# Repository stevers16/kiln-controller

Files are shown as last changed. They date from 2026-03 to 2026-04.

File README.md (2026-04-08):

# Kiln Controller

A MicroPython-based lumber drying kiln controller for a passive solar kiln in the
Georgian Bay area of Ontario. Designed for drying hardwood lumber (maple and beech,
0.5--1 inch thick) using multi-stage schedules derived from USDA Forest Products
Laboratory references (FPL-GTR-57 and FPL-GTR-118).

The kiln is approximately 5 ft x 2 ft x 3 ft, heated passively by solar gain with a
500W ceramic PTC backup heater for shoulder-season use. A Raspberry Pi Pico 2W
controls all kiln hardware. Telemetry is transmitted over LoRa (~200m) to a Raspberry
Pi 4 at the cottage, which stores data in SQLite and serves a REST API for a Kivy
mobile app.

---

## Hardware

| Subsystem | Component |
|---|---|
| MCU | Raspberry Pi Pico 2W |
| Temperature / RH | 2x SHT31-D (I2C, 0x44 / 0x45) |
| Moisture probes | Resistive, voltage divider, AC excitation |
| Exhaust fan | Foxconn PVA080G12Q 80mm PWM, tach feedback |
| Circulation fans | 3x Thermalright TL-C12C 120mm PWM |
| Vent dampers | 2x MG90S servo (intake + exhaust) |
| Backup heater | 500W PTC + Fotek SSR-25DA + RY85 thermal fuse |
| Current monitoring | 2x INA219 (12V rail + 5V rail) |
| Display | JC035-HVGA-ST-02 3.5" UART serial, 320x480 |
| SD card | SPI micro SD (logging) |
| LoRa radio | AI-Thinker Ra-02 433 MHz (SX1278), TX-only |
| Remote server | Raspberry Pi 4 with Ra-02 receiver |

---

## Schematic and custom PCB

KiCad 9.0 project with schematic and custom PCB layout is in the PCB folder.

---

## Firmware (Pico 2W -- MicroPython)

All hardware drivers live in `lib/`. Every module is class-based, accepts pin numbers
as constructor arguments, and follows the pattern established in `lib/exhaust.py`.

| Module | Function |
|---|---|
| `lib/exhaust.py` | 80mm exhaust fan -- PWM + tach |
| `lib/circulation.py` | 3x 120mm circulation fans -- PWM group |
| `lib/vents.py` | Intake + exhaust damper servos |
| `lib/heater.py` | SSR on/off control |
| `lib/SHT31sensors.py` | Dual SHT31 temperature + RH |
| `lib/moisture.py` | Resistive moisture probes, species correction |
| `lib/current.py` | INA219 DC current monitoring |
| `lib/lora.py` | SX1278 LoRa transmitter (TX-only, register polling) |
| `lib/display.py` | UART serial display driver + button + page system |
| `lib/sdcard.py` | SPI SD card mount/unmount wrapper |
| `lib/logger.py` | Event log + CSV data log to SD card |
| `lib/schedule.py` | Multi-stage drying schedule controller |
| `main.py` | Entry point -- asyncio control loop + WiFi AP + REST API |
| `config.py` | Deployment configuration (SSID, key, LoRa params) |

Drying schedules are stored as JSON in `schedules/` and loaded from the SD card at
runtime. Schedules are included for hard maple and beech at 0.5 in and 1 in thickness.

### Deploying to the Pico

```
python update_lib.py
```

This copies `main.py`, `config.py`, and all `lib/` files to the Pico in one step.
The MicroPython SPI SD card driver must be deployed as `sdcard_driver.py`:

```
mpremote cp sdcard_driver.py :sdcard_driver.py
```

### Running tests

```
mpremote run test_modules.py
```

Tests all 12 modules in sequence and reports pass/fail. Does not start WiFi or the
control loop.

---

## Cottage-side architecture (Pi4)

```
Pico --> SPI1 --> Ra-02 ~~LoRa~~ Ra-02 --> SPI0 --> Pi4 kiln_server
                                                 --> SQLite
                                                 --> REST API :8080 --> Kivy app
                                                 --> ntfy.sh --> phone
```

The `kiln_server/` Python package (in progress) runs as a systemd service on the Pi4.
It receives LoRa packets from the Pico, writes telemetry and alerts to SQLite, serves
a REST API for the mobile app, and pushes fault alerts via ntfy.sh.

The Pico also runs a WiFi AP and exposes its own REST API (port 80) for direct
local control when within range.

---

## Drying schedules

Schedules follow USDA FPL kiln-drying recommendations:

- Hard maple (T3-C2): `schedules/maple_05in.json`, `schedules/maple_1in.json`
- Beech (T4-C3): `schedules/beech_05in.json`, `schedules/beech_1in.json`

Each schedule has 9 stages: 7 drying stages + equalizing + conditioning. Stage advance
is automatic (MC% + minimum time) for drying stages, and time-only for
equalizing/conditioning. Manual advance is available via the REST API.

---

## Status

Pico firmware is at the integration stage. All 12 `lib/` modules are complete and
hardware-tested. `main.py` is implemented and pending full hardware integration test.
The Pi4 `kiln_server` daemon and Kivy mobile app are next.

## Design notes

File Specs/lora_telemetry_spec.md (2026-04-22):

# LoRa Telemetry Module -- Hardware & Firmware Spec
**Kiln Controller Project**
**Status:** Ra-02 modules on order (arriving ~2 weeks); Pi4 daemon not yet implemented
**Scope:** Covers Pico-side LoRa transmitter and Pi4-side LoRa receiver + data server

---

## Overview

The kiln Pico 2W transmits periodic telemetry and fault alerts via a LoRa radio link to a
Raspberry Pi 4 at the cottage (~200m, wooded path following cleared driveway). The Pi4 has
a second Ra-02 module wired directly to its SPI bus. A Python daemon receives LoRa packets,
writes them to a SQLite database, serves a REST API for the Kivy phone app, and pushes
fault alerts via ntfy.sh.

```
Pico 2W --> SPI1 --> Ra-02 (433 MHz) ~~LoRa~~ Ra-02 --> SPI0 --> Pi4 daemon --> SQLite
                                                                              --> REST API --> Kivy app
                                                                              --> ntfy.sh --> phone
```

**Pico-side is transmit-only.** The Pico never listens for incoming LoRa packets. All
parameter changes and commands to the kiln are handled via the Wi-Fi AP / REST API interface.
DIO0 is not connected on the Pico side -- TX completion is confirmed by polling the SX1278
IRQ flags register over SPI (see Firmware section). This frees GP20 for use as the display
button input.

No ESP32 or MQTT broker is required in the deployed system. The ESP32-WROOM-32 devboard
(owned) is useful for bench testing the Pico LoRa transmitter before the Pi4 daemon is
ready, but is not part of the production architecture.

---

## Hardware

### LoRa Modules

**Part:** AI-Thinker Ra-02 (SX1278, 433 MHz) with IPEX antenna
**Quantity:** 2 (ordered from AliExpress)
**Critical:** 433 MHz variant only -- NOT the 915 MHz Ra-01 or Ra-01S.

**Ra-02 electrical characteristics:**
- Supply voltage: 3.3V (NOT 5V tolerant -- will be damaged by 5V)
- Logic levels: 3.3V
- Interface: SPI (mode 0)
- Max SPI clock: 10 MHz (use 1-4 MHz in practice)
- Current draw: ~120 mA TX, ~12 mA RX, ~1.5 mA idle

**Antenna:** IPEX (u.FL) connector with antenna included in order.

---

### Pico-Side Wiring (Kiln Enclosure)

The Ra-02 connects via SPI1 on the Pico using the default SPI1 pin block (GP10-GP13).
Moisture probe AC excitation channels were moved from GP12/GP13 to GP6/GP7 to free the
full SPI1 block for LoRa -- this is already reflected in `lib/moisture.py` (GP6/GP7).

DIO0 is **not connected** on the Pico side. TX completion is confirmed by polling the
SX1278 IRQ flags register over SPI (see Firmware section). GP20 is therefore free for
use as the display button input, which is its current assignment in `lib/display.py`.

**Power:**

| Ra-02 Pin | Pico Pin | Notes |
|---|---|---|
| VCC | 3.3V (Pin 36) | Ra-02 is 3.3V only  |
| GND | GND (Pin 38)  | Common ground |

**SPI and control:**

| Ra-02 Pin | Pico GPIO | Physical Pin | Notes |
|---|---|---|---|
| SCK | GP10 | Pin 14 | SPI1 SCK (default) |
| MOSI | GP11 | Pin 15 | SPI1 TX (default) |
| MISO | GP12 | Pin 16 | SPI1 RX (default) |
| NSS (CS)  | GP13 | Pin 17 | SPI1 CS (default) -- active low |
| RST | GP28 | Pin 34 | Reset -- active low |
| DIO0 | -- | not connected| Not needed (TX-only, polling) |

**GPIO map (Pico GPIO Map tab in BOM):**

| GPIO | Function | Notes |
|---|---|---|
| GP6  | Digital OUT -- AC excite Ch1  | Moisture probe (moved from GP12) |
| GP7  | Digital OUT -- AC excite Ch2  | Moisture probe (moved from GP13) |
| GP10 | SPI1 SCK -- LoRa Ra-02 | |
| GP11 | SPI1 TX (MOSI) -- LoRa Ra-02  | |
| GP12 | SPI1 RX (MISO) -- LoRa Ra-02  | |
| GP13 | SPI1 CS -- LoRa Ra-02 | Active low |
| GP20 | Digital IN -- Display button  | Freed from LoRa DIO0; see display spec |
| GP28 | Digital OUT -- LoRa RST | |

**Decoupling:** Place a 100 nF ceramic capacitor between Ra-02 VCC and GND as close to
the module as possible. The Ra-02 RF switching causes supply transients.

---

### Pi4-Side Wiring (Cottage)

The Ra-02 wires directly to the Pi4 GPIO header via SPI0. The Pi4 GPIO is 3.3V -- no
level shifting required. SPI must be enabled on the Pi4 via:
`sudo raspi-config` -> Interface Options -> SPI -> Enable

DIO0 IS connected on the Pi4 side because the daemon uses interrupt-driven receive.

**Power:**

| Ra-02 Pin | Pi4 Pin | Notes |
|---|---|---|
| VCC | Pin 17 (3.3V) | Ra-02 is 3.3V only |
| GND | Pin 20 (GND)  | Common ground |

**SPI and control (SPI0, CE0):**

| Ra-02 Pin | Pi4 GPIO | Pi4 Physical Pin | Notes |
|---|---|---|---|
| SCK | GPIO11 | Pin 23 | SPI0 SCLK |
| MOSI | GPIO10 | Pin 19 | SPI0 MOSI |
| MISO | GPIO9 | Pin 21 | SPI0 MISO |
| NSS (CS)  | GPIO8 | Pin 24 | SPI0 CE0 -- active low |
| DIO0 | GPIO25 | Pin 22 | RX done interrupt (input) |
| RST | GPIO17 | Pin 11 | Reset line (output) |

**Decoupling:** 100 nF ceramic capacitor between Ra-02 VCC and GND.

---

## Firmware Architecture

### Pico Side -- `lib/lora.py`

A mock implementation already exists and passes hardware tests. This section describes
the real driver to replace it once Ra-02 hardware arrives. Follow the existing module
pattern (class-based, pin numbers as constructor args, matching `exhaust.py` template).

```python
# Instantiation example (from main.py)
lora = LoRa(
    spi_id=1,
    sck=10, mosi=11, miso=12,
    cs=13, rst=28,
    frequency=433_000_000
)
```

Note: no `irq` parameter -- DIO0 is not connected on the Pico side.

**Class responsibilities:**
- Initialise SPI1 using default pin block:
  `SPI(1, baudrate=1_000_000, sck=Pin(10), mosi=Pin(11), miso=Pin(12))`
- Configure SX1278 registers via SPI (frequency, bandwidth, spreading factor, coding rate)
- `send(payload: bytes) -> bool` -- blocking TX with polling-based completion (see below)
- `send_telemetry(data: dict) -> bool` -- serialises dict to JSON, calls `send()`
- `send_alert(code: str, message: str) -> bool` -- 3x retry with 2s spacing
- `reset()` -- pulses RST pin low for 10ms
- `is_mock` property returns False (distinguishes from mock implementation)
- TX-only -- no receive path on Pico side
- Accepts optional `logger=None`; source string `"lora"`; logs on init, send success,
  send timeout, and RST events

**TX completion -- register polling (no DIO0 needed):**

Because DIO0 is not connected, TX completion is determined by polling the SX1278 IRQ flags
register (RegIrqFlags, address 0x12) over SPI. The TxDone flag is bit 3 (mask 0x08).

Procedure in `send()`:
1. Write payload to FIFO, set mode to TX (RegOpMode = 0x83)
2. Poll RegIrqFlags in a loop at 5 ms intervals until bit 3 (TxDone) is set, or 2000 ms
   timeout is reached
3. Clear all IRQ flags by writing 0xFF to RegIrqFlags
4. Return device to sleep mode (RegOpMode = 0x80)
5. Return True on TxDone, False on timeout (caller logs `LORA_TIMEOUT` alert)

For SF9 / 125 kHz / 4:5 coding rate, airtime for a 100-byte payload is approximately
330 ms. The 2000 ms timeout gives comfortable headroom across all expected payload sizes.
This approach is functionally equivalent to interrupt-driven TX confirmation for a
transmit-only module on a 30-second heartbeat schedule.

**Suggested LoRa RF parameters:**

| Parameter | Value | Notes |
|---|---|---|
| Frequency | 433.0 MHz | Within 433.05-434.79 MHz ISM band (Canada RSS-210) |
| Bandwidth | 125 kHz | Standard |
| Spreading Factor | SF9 | Good for wooded 200m; increase if link marginal |
| Coding Rate | 4/5 | |
| TX Power | 17 dBm | Ra-02 maximum; reduce if interference observed |
| Preamble | 8 symbols | Default |

**Transmission schedule:**
- Telemetry heartbeat: every 30 seconds (driven by `schedule.py` tick)
- Fault alerts: immediate on detection, retried up to 3x with 2s spacing
- SPI1 (LoRa) and SPI0 (SD card) are separate buses -- no contention

**Fault codes in telemetry packet (added by error_checking_spec.md):**

The LoRa telemetry packet now includes an optional `faults` field: a flat
JSON array of fault code strings (e.g. `"faults":["SD_FAIL","LORA_TIMEOUT"]`).
Only tier="fault" codes are included (not notices or info). The list is
trimmed from the back until the total packet fits within the SX1278 255-byte
FIFO limit. With the existing ~231-byte base payload, typically 0-1 short
fault codes fit. If no faults are active, the field is omitted entirely.

The rich `fault_details` list (with code, source, message, tier per fault)
is served exclusively over the Pico HTTP `/status` endpoint. The Pi4 daemon
receives only the flat code list over LoRa and can look up descriptions
from a static table or simply display the codes.

**Duty cycle note:** At 30s intervals TX duty cycle is well under 1% -- within the 10%
limit for 433 MHz ISM use in Canada.

---

### Pi4 Side -- `kiln_server/` Python package

The Pi4 runs a single Python process that owns the Ra-02 via SPI, writes all received
data to SQLite, serves a REST API to the Kivy app, and pushes alerts via ntfy.sh.

**Python dependencies:**
- `spidev` -- SPI bus access on Pi4
- `RPi.GPIO` -- GPIO interrupt handling for DIO0
- `pysx127x` or equivalent SX1276/78 driver (or port register sequences from the Pico
  driver directly -- keeps both sides symmetric and eliminates a third-party dependency)
- `flask` or `fastapi` -- REST API
- `requests` -- ntfy.sh HTTP POST
- `sqlite3` -- stdlib, no install required

**Package structure:**

```
kiln_server/
  __main__.py       -- entry point; starts receiver loop and REST API server
  config.py         -- Pi4 GPIO pins, DB path, ntfy topic, API port, LoRa params
  lora_receiver.py  -- SX1278 init, receive loop, DIO0 interrupt handler
  database.py       -- SQLite open/init, insert_telemetry(), insert_alert(), query functions
  api.py            -- REST route definitions
  notifier.py       -- ntfy.sh POST helper
  schema.sql        -- SQLite CREATE TABLE statements (also executed by database.py on init)
```

**`config.py` (the only file that changes between bench and cottage deployment):**

```python
# Bench Pi4 (home)
DB_PATH       = "/home/srelias/CottageKiln/kiln_data.db"
NTFY_TOPIC    = "your-unique-kiln-topic"
API_PORT      = 8080

# Pi4 GPIO pin numbers (BCM numbering -- same on bench and cottage)
LORA_RST_PIN  = 17
LORA_DIO0_PIN = 25
LORA_SPI_BUS  = 0
LORA_SPI_DEV  = 0    # CE0

# LoRa RF params -- must match Pico side
LORA_FREQ_HZ  = 433_000_000
LORA_SF       = 9
LORA_BW_HZ    = 125_000
```

**Operation:**
1. On start: initialise Ra-02 via SPI, configure for continuous receive mode
2. DIO0 interrupt fires on packet received -> read payload, parse JSON
3. Write telemetry record to SQLite `telemetry` table with Pi4 wall-clock timestamp
4. If packet is an alert, write to `alerts` table and POST to ntfy.sh
5. REST API runs concurrently (thread or async) serving Kivy app queries
6. Daemon runs continuously; started at boot via systemd unit file

---

## SQLite Schema

```sql
-- schema.sql

CREATE TABLE IF NOT EXISTS telemetry (
    id              INTEGER PRIMARY KEY AUTOINCREMENT,
    ts              INTEGER NOT NULL,   -- Unix timestamp from Pico RTC
    received_at     INTEGER NOT NULL,   -- Unix timestamp on Pi4 (wall clock)
    stage           TEXT,
    temp_lumber     REAL,
    temp_intake     REAL,
    humidity_lumber REAL,
    humidity_intake REAL,
    mc_channel_1    REAL,
    mc_channel_2    REAL,
    exhaust_fan_rpm INTEGER,
    exhaust_fan_pct INTEGER,
    circ_fan_on     INTEGER,            -- 0/1
    heater_on       INTEGER,            -- 0/1
    vent_open       INTEGER,            -- 0/1
    lora_rssi       INTEGER,            -- dBm, measured at Pi4 receiver
    lora_snr        REAL
);

CREATE TABLE IF NOT EXISTS alerts (
    id          INTEGER PRIMARY KEY AUTOINCREMENT,
    ts          INTEGER NOT NULL,
    received_at INTEGER NOT NULL,
    code        TEXT NOT NULL,
    message     TEXT,
    value       REAL,
    limit_val   REAL,
    lora_rssi   INTEGER,
    lora_snr    REAL
);

CREATE TABLE IF NOT EXISTS runs (
    id            INTEGER PRIMARY KEY AUTOINCREMENT,
    started_at    INTEGER NOT NULL,
    ended_at      INTEGER,
    schedule_name TEXT,
    completed     INTEGER DEFAULT 0     -- 0/1
);

CREATE INDEX IF NOT EXISTS idx_telemetry_ts ON telemetry(ts);
CREATE INDEX IF NOT EXISTS idx_alerts_ts    ON alerts(ts);
```

---

## REST API Endpoints

Base URL: `http://<pi4-ip>:8080`

All responses are JSON.

| Method | Path | Description |
|---|---|---|
| GET | `/status`  | Latest telemetry record |
| GET | `/history` | Time-series data; params: `start`, `end` (Unix ts), `fields` (CSV list)|
| GET | `/alerts`  | Recent alerts; param: `limit` (default 50) |
| GET | `/runs` | List of drying runs with start/end times |
| GET | `/health`  | Daemon uptime, last packet received timestamp, total packet count |

**Example `/history` response (columnar format for Kivy plotting):**

```json
{
  "fields": ["ts", "temp_lumber", "humidity_lumber", "mc_channel_1"],
  "rows": [
    [1700000000, 52.3, 61.2, 18.4],
    [1700000030, 52.5, 60.9, 18.3]
  ]
}
```

The columnar format minimises payload size for long runs -- more efficient than an array
of objects when plotting hundreds or thousands of data points.

---

## Alert Codes

Alerts are generated on the Pico and transmitted as LoRa packets. The Pi4 daemon writes
them to the `alerts` table and triggers ntfy.sh notifications.

| Code | Source | Condition |
|---|---|---|
| `OVER_TEMP` | Pico | Either SHT31 zone exceeds stage limit |
| `SENSOR_FAIL` | Pico | SHT31 read error or timeout |
| `FAN_STALL` | Pico | Exhaust fan tach reads 0 RPM when commanded on |
| `HEATER_TIMEOUT` | Pico | SSR on continuously beyond safety threshold |
| `SD_FAIL` | Pico | SD card write error |
| `LORA_TIMEOUT` | Pico | TxDone flag not seen within 2000 ms polling window |
| `STAGE_COMPLETE` | Pico | Drying schedule stage transition (informational) |
| `SCHEDULE_DONE`  | Pico | Full drying schedule completed |

---

## Phone Notifications -- ntfy.sh

The Pi4 daemon POSTs directly to ntfy.sh on alert receipt. No MQTT broker or separate
notification script required.

```python
# notifier.py
import requests

def send_alert(topic, code, message):
    try:
        requests.post(
            f"https://ntfy.sh/{topic}",
            data=f"{code}: {message}",
            headers={"Priority": "high", "Tags": "warning"},
            timeout=5
        )
    except Exception:
        pass  # never let notification failure affect daemon operation
```

Install the ntfy app on phone and subscribe to the configured topic name. Alert delivery
is best-effort -- the kiln runs safely whether or not the notification goes through.

---

## Systemd Service

```ini
# /etc/systemd/system/kiln-server.service
[Unit]
Description=Kiln LoRa Telemetry Server
After=network.target

[Service]
ExecStart=/usr/bin/python3 -m kiln_server
WorkingDirectory=/home/srelias/CottageKiln/kiln_server
Restart=always
RestartSec=5
User=pi

[Install]
WantedBy=multi-user.target
```

Enable: `sudo systemctl enable kiln-server && sudo systemctl start kiln-server`

---

## Bench Test Plan

Both Pi4 units are identical -- the bench test exactly duplicates the cottage deployment.
Only `config.py` changes between environments.

**End-to-end bench test:**
1. Wire bench Pi4 to Ra-02 per Pi4 wiring table above
2. Enable SPI: `sudo raspi-config` -> Interface Options -> SPI -> Enable; reboot
3. Install dependencies: `pip install spidev RPi.GPIO flask requests`
4. Start daemon: `python -m kiln_server`
5. Wire Pico to Ra-02 per Pico wiring table (DIO0 unconnected); flash real `lib/lora.py`
6. Run `lora_test.py` on Pico -- transmit a packet every 5s
7. Verify TxDone flag is seen via register polling within expected airtime (~330 ms for 100 bytes at SF9)
8. Confirm rows in SQLite: `sqlite3 kiln_data.db "SELECT * FROM telemetry LIMIT 5;"`
9. Confirm REST API: `curl http://localhost:8080/status`
10. Trigger a test alert from Pico; confirm ntfy.sh notification on phone
11. Force a `LORA_TIMEOUT` by asserting CS high during TX; verify alert code fires correctly
12. Short-range RSSI will be very strong (-40 to -60 dBm) -- that is expected

**Pre-deployment check at cottage:**
1. Deploy cottage Pi4 with identical setup; update `config.py` for cottage network
2. Start `kiln_server` as systemd service
3. Power Pico at kiln location
4. Query `/health` -- watch `last_packet_ts` and packet count increment
5. Target RSSI: better than -115 dBm at SF9. Expect -90 to -105 dBm for 200m wooded path.
6. If RSSI marginal, increase SF to SF10 or SF11 in `config.py` and Pico constructor
   (3-6 dB link budget gain per SF step, at cost of longer air time)

---

## BOM

| Item | Qty | Est. Cost (CAD) | Notes |
|---|-----|---|---|
| AI-Thinker Ra-02 433 MHz + IPEX antenna | 2 | ~$8 | Ordered from AliExpress |
| 100 nF ceramic capacitor | 2 | ~$0.10 | Decoupling; likely in stock |
| Female-female jumper wires | 6 | ~$1 | Pi4 GPIO header connection |

Both Pi4 units are already owned. ESP32-WROOM-32 devboard retained as an optional tool
for bench-testing Pico LoRa TX before the Pi4 daemon is ready; not part of production
system.

---

## Open Items

- [x] Ra-02 modules ordered (arriving ~2 weeks)
- [x] GPIO pin assignments finalised: GP10-13 SPI1, GP28 RST; DIO0 not connected on Pico
- [x] GP20 confirmed as display button (freed from LoRa DIO0)
- [x] Moisture probe AC excitation confirmed on GP6/GP7 in `lib/moisture.py`
- [x] Architecture decision: Ra-02 wired directly to Pi4; no ESP32 in production
- [ ] Implement real `lib/lora.py` on Pico to replace mock (after Ra-02 arrives)
- [ ] Implement `kiln_server/` Python package (Claude Code)
- [ ] Enable SPI on bench Pi4 and wire Ra-02
- [ ] Bench test: Pico TX -> Pi4 RX -> SQLite -> REST API -> ntfy.sh
- [ ] Choose ntfy.sh topic name
- [ ] Write and enable systemd unit file on cottage Pi4
- [ ] Kivy app REST API integration (separate spec, to be written)

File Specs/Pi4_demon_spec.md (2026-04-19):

# PI4_DAEMON_SPEC.md

Spec for the `kiln_server` Python daemon running on the Raspberry Pi 4 at the
cottage. This document supersedes the informal daemon sketch in
`lora_telemetry_spec.md` and adds all endpoints and database details required
by the Kivy app.

---

## Overview

The Pi4 daemon (`kiln_server`) is a long-running Python process that:

1. Receives LoRa telemetry packets from the kiln Pico via a Ra-02 SX1278 module
   wired to the Pi4 SPI0 bus
2. Writes all telemetry and alerts to a SQLite database
3. Serves a read-only REST API (port 8080) for the Kivy app
4. Pushes fault alerts to a phone via ntfy.sh

No control commands are relayed to the Pico from the Pi4. The Pi4 API is
strictly read-only. Control requires direct AP connection from the app to the
Pico.

---

## Package Structure

```
kiln_server/
    __main__.py         -- entry point; starts all threads/tasks
    config.py           -- environment-specific settings (only file that differs
                           between bench and cottage deployments)
    lora_receiver.py    -- SX1278 SPI init, DIO0 interrupt, receive loop
    database.py         -- SQLite schema, insert and query functions
    api.py              -- Flask REST endpoints
    notifier.py         -- ntfy.sh HTTP POST
    schema.sql          -- SQL schema (applied on first run)
```

---

## Hardware

Ra-02 SX1278 wired to Pi4 GPIO header via SPI0. See `lora_telemetry_spec.md`
for full wiring table. SPI must be enabled via `raspi-config`.

---

## config.py

The only file that differs between bench and cottage deployments.

```python
# config.py

ENVIRONMENT   = "cottage"          # "bench" or "cottage" -- shown in /health

# LoRa SPI
SPI_BUS       = 0
SPI_CE        = 0                  # CE0 = GPIO8
DIO0_PIN      = 25                 # GPIO25
RST_PIN       = 17                 # GPIO17
LORA_SF       = 9
LORA_FREQ_MHZ = 433.0

# Database
DB_PATH       = "/home/srelias/CottageKiln/kiln_data.db"

# API
API_HOST      = "0.0.0.0"
API_PORT      = 8080

# Notifications
NTFY_TOPIC    = "kiln-cottage-abc123"   # choose a unique topic name
NTFY_URL      = "https://ntfy.sh"

# Alert suppression (do not re-notify same code within this window)
ALERT_SUPPRESS_S = 1800            # 30 minutes
```

---

## SQLite Schema

Applied from `schema.sql` on first run if tables do not exist.

```sql
CREATE TABLE IF NOT EXISTS telemetry (
    id              INTEGER PRIMARY KEY AUTOINCREMENT,
    ts              INTEGER NOT NULL,       -- Unix timestamp from Pico RTC
    received_at     INTEGER NOT NULL,       -- Unix timestamp on Pi4 (wall clock)
    run_id          INTEGER,                -- FK to runs.id (nullable)
    stage           INTEGER,
    stage_type      TEXT,
    temp_lumber     REAL,
    temp_intake     REAL,
    rh_lumber       REAL,
    rh_intake       REAL,
    mc_channel_1    REAL,
    mc_channel_2    REAL,
    heater_on       INTEGER,                -- 0/1
    vent_open       INTEGER,                -- 0/1
    vent_reason     TEXT,
    exhaust_fan_pct INTEGER,
    exhaust_fan_rpm INTEGER,
    circ_fan_on     INTEGER,                -- 0/1
    circ_fan_pct    INTEGER,
    current_12v_ma  REAL,
    current_5v_ma   REAL,
    lora_rssi       INTEGER,                -- dBm measured at Pi4
    lora_snr        REAL
);

CREATE TABLE IF NOT EXISTS alerts (
    id          INTEGER PRIMARY KEY AUTOINCREMENT,
    ts          INTEGER NOT NULL,
    received_at INTEGER NOT NULL,
    run_id      INTEGER,
    code        TEXT NOT NULL,
    message     TEXT,
    value       REAL,
    limit_val   REAL,
    lora_rssi   INTEGER,
    lora_snr    REAL
);

CREATE TABLE IF NOT EXISTS runs (
    id            INTEGER PRIMARY KEY AUTOINCREMENT,
    started_at    INTEGER NOT NULL,
    ended_at      INTEGER,
    schedule_name TEXT,
    label         TEXT,
    completed     INTEGER DEFAULT 0         -- 0/1
);

CREATE INDEX IF NOT EXISTS idx_telemetry_ts    ON telemetry(ts);
CREATE INDEX IF NOT EXISTS idx_telemetry_run   ON telemetry(run_id);
CREATE INDEX IF NOT EXISTS idx_alerts_ts       ON alerts(ts);
CREATE INDEX IF NOT EXISTS idx_alerts_run      ON alerts(run_id);
```

---

## LoRa Packet Parsing

The Pico transmits two packet types:

**Telemetry packet** (JSON, transmitted every 30s during a run):

```json
{
  "type": "telemetry",
  "ts": 1711900000,
  "stage": 2,
  "stage_type": "drying",
  "temp_lumber": 48.7,
  "rh_lumber": 71.2,
  "temp_intake": 22.4,
  "rh_intake": 55.1,
  "mc_channel_1": 27.3,
  "mc_channel_2": 26.8,
  "heater_on": false,
  "vent_open": false,
  "vent_reason": null,
  "exhaust_fan_pct": 0,
  "exhaust_fan_rpm": 0,
  "circ_fan_on": true,
  "circ_fan_pct": 75,
  "current_12v_ma": 412.0,
  "current_5v_ma": 89.0
}
```

**Alert packet** (semicolon-delimited ASCII string):

```
ALERT;{code};stage={n};temp={t:.1f};rh={r:.1f}[;{extra}]
```

Examples:
```
ALERT;rh_out_of_range;stage=2;temp=48.7;rh=82.1
ALERT;heater_fault;stage=3;temp=45.2;rh=70.1
ALERT;equalizing_start;stage=7;temp=63.0;rh=55.0;add water pans if needed
ALERT;sensor_failure;stage=2
ALERT;run_complete;stage=8;temp=63.0;rh=48.0
```

The daemon detects packet type by attempting JSON parse first. If JSON parse
fails, treat as an alert string. Unknown formats are logged and discarded.

**Run lifecycle detection:**
- `run_started` alert: open a new `runs` row, record `started_at`
- `run_complete` alert: close the active `runs` row, set `ended_at` and
  `completed=1`
- If daemon restarts with an open run in the DB, leave it open -- the Pico will
  send a `run_complete` alert when the run ends

**run_id assignment:**
- All telemetry and alert rows received while a run is open get the current
  `runs.id` as `run_id`
- Rows received outside a run have `run_id = NULL`

---

## REST API Endpoints

Base URL: `http://<pi4-ip>:8080`

All responses are JSON. No authentication required (LAN-only, read-only).

---

### GET /health

Daemon status and environment info.

**Response:**

```json
{
  "status": "ok",
  "environment": "cottage",
  "uptime_s": 86412,
  "last_packet_ts": 1711900000,
  "last_packet_age_s": 28,
  "total_packets": 8642,
  "db_size_bytes": 2048000,
  "lora_rssi_last": -94,
  "lora_snr_last": 7.2
}
```

---

### GET /status

Latest telemetry record from the database.

**Response:**

```json
{
  "ts": 1711900000,
  "received_at": 1711900002,
  "run_id": 3,
  "stage": 2,
  "stage_type": "drying",
  "temp_lumber": 48.7,
  "rh_lumber": 71.2,
  "temp_intake": 22.4,
  "rh_intake": 55.1,
  "mc_channel_1": 27.3,
  "mc_channel_2": 26.8,
  "heater_on": false,
  "vent_open": false,
  "vent_reason": null,
  "exhaust_fan_pct": 0,
  "exhaust_fan_rpm": 0,
  "circ_fan_on": true,
  "circ_fan_pct": 75,
  "current_12v_ma": 412.0,
  "current_5v_ma": 89.0,
  "lora_rssi": -94,
  "lora_snr": 7.2
}
```

Returns `{"status": "no_data"}` if no telemetry rows exist.

---

### GET /history

Time-series telemetry data for graphing.

**Query parameters:**

| Parameter | Type | Default | Notes |
|---|---|---|---|
| `start` | int | run start | Unix timestamp |
| `end` | int | now | Unix timestamp |
| `fields` | string | all | Comma-separated column names |
| `resolution` | int | 1 | Return every Nth row (server-side decimation) |
| `run_id` | int | latest run | Filter by run |

Available fields:
```
ts, received_at, stage, stage_type, temp_lumber, temp_intake, rh_lumber,
rh_intake, mc_channel_1, mc_channel_2, heater_on, vent_open, vent_reason,
exhaust_fan_pct, exhaust_fan_rpm, circ_fan_on, current_12v_ma, current_5v_ma,
lora_rssi, lora_snr
```

**Response (columnar format):**

```json
{
  "fields": ["ts", "temp_lumber", "rh_lumber", "mc_channel_1"],
  "rows": [
    [1711900000, 48.7, 71.2, 27.3],
    [1711900030, 48.9, 70.8, 27.1]
  ],
  "run_id": 3,
  "row_count": 2
}
```

**Implementation note:** Decimation is applied in SQL using `WHERE rowid % N = 0`
approximation or by row-number filtering in Python after query. For `resolution=1`
(no decimation), return all rows in range.

---

### GET /alerts

Recent alerts from the database.

**Query parameters:**

| Parameter | Type | Default | Notes |
|---|---|---|---|
| `limit` | int | 50 | Max rows |
| `run_id` | int | all | Filter by run |
| `code` | string | all | Filter by alert code |

**Response:**

```json
{
  "alerts": [
    {
      "id": 42,
      "ts": 1711900000,
      "received_at": 1711900002,
      "run_id": 3,
      "code": "rh_out_of_range",
      "message": "ALERT;rh_out_of_range;stage=2;temp=48.7;rh=82.1",
      "value": 82.1,
      "limit_val": 78.0,
      "lora_rssi": -94,
      "lora_snr": 7.2
    }
  ],
  "count": 1
}
```

Alerts are returned in reverse chronological order (newest first).

---

### GET /runs

List of all drying runs.

**Query parameters:**

| Parameter | Type | Default | Notes |
|---|---|---|---|
| `limit` | int | 20 | Max rows |

**Response:**

```json
{
  "runs": [
    {
      "id": 3,
      "started_at": 1711800000,
      "ended_at": 1711900000,
      "duration_h": 27.8,
      "schedule_name": "Hard Maple 1 inch",
      "label": "Workshop maple batch 1",
      "completed": true,
      "telemetry_count": 3336,
      "alert_count": 4
    }
  ]
}
```

An active run has `ended_at: null` and `completed: false`.
`duration_h` is null for active runs.

---

## Notification -- ntfy.sh

```python
# notifier.py

import requests

def send_alert(topic, code, message):
    try:
        requests.post(
            f"https://ntfy.sh/{topic}",
            data=f"{code}: {message}",
            headers={
                "Priority": "high",
                "Tags": "warning",
                "Title": "Kiln Alert"
            },
            timeout=5
        )
    except Exception:
        pass    # never let notification failure affect daemon operation
```

**Alert suppression:** The daemon tracks the last notification time per alert
code (in memory). The same code is not re-notified within `ALERT_SUPPRESS_S`
seconds (default 30 minutes). One-shot alerts (`run_complete`, `equalizing_start`,
`conditioning_start`) bypass suppression.

**Phone setup:** Install the ntfy app and subscribe to the configured topic name.
Topic name is displayed in the Kivy app Settings screen (from `/health` response).

---

## Systemd Service

```ini
# /etc/systemd/system/kiln-server.service

[Unit]
Description=Kiln LoRa Telemetry Server
After=network.target

[Service]
ExecStart=/usr/bin/python3 -m kiln_server
WorkingDirectory=/home/srelias/CottageKiln/kiln_server
Restart=always
RestartSec=5
User=pi
Environment=PYTHONUNBUFFERED=1

[Install]
WantedBy=multi-user.target
```

Enable and start:
```
sudo systemctl enable kiln-server
sudo systemctl start kiln-server
```

View logs:
```
journalctl -u kiln-server -f
```

---

## Dependencies

```
flask
spidev
RPi.GPIO
requests
```

Install:
```
pip3 install flask spidev RPi.GPIO requests
```

---

## Bench vs. Cottage Deployment

The bench Pi4 and cottage Pi4 are identical in software. Only `config.py` differs:

| Setting | Bench | Cottage |
|---|---|---|
| `ENVIRONMENT` | "bench" | "cottage" |
| `DB_PATH` | `/home/srelias/CottageKiln/kiln_bench.db` | `/home/srelias/CottageKiln/kiln_data.db` |
| `NTFY_TOPIC` | (optional bench topic) | (production topic) |

The Kivy app Settings screen shows the `ENVIRONMENT` value from `/health` so the
operator can confirm which Pi4 they are connected to.

---

## Bench Test Plan

1. Enable SPI on bench Pi4: `sudo raspi-config` -> Interface Options -> SPI -> Enable; reboot
2. Wire Ra-02 to Pi4 per `lora_telemetry_spec.md` wiring table
3. Install dependencies
4. Set `config.py` to `ENVIRONMENT = "bench"`
5. Start daemon: `python3 -m kiln_server`
6. Wire Pico to Ra-02 per Pico wiring; flash real `lib/lora.py`
7. Run `lora_test.py` on Pico -- transmit packets every 5s
8. Confirm SQLite rows: `sqlite3 kiln_bench.db "SELECT * FROM telemetry LIMIT 5;"`
9. Confirm REST API: `curl http://localhost:8080/status`
10. Trigger a test alert from Pico; confirm ntfy.sh notification on phone
11. Query `/health` -- confirm `last_packet_age_s` increments then resets

---

## Open Items

- [ ] Implement `kiln_server/` Python package per this spec
- [ ] Enable SPI on bench Pi4 and wire Ra-02
- [ ] Bench end-to-end test (steps above)
- [ ] Choose ntfy.sh topic name for cottage deployment
- [ ] Write and enable systemd unit file on cottage Pi4
- [ ] Pre-deployment RSSI check at cottage (target better than -115 dBm at SF9)

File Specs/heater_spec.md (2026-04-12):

# Spec: lib/heater.py

## Purpose

Controls the 120V backup ceramic heater via a Fotek SSR-25DA solid-state relay.
The SSR is driven by a digital GPIO output through a current-limiting resistor.
Safety logic (temperature limits, interlocks) is the responsibility of the main
controller -- heater.py is a simple on/off driver with logging.

---

## Hardware

- **SSR:** Fotek SSR-25DA, DC control input 3-32V, direct Pico GPIO drive
- **Control pin:** GP16 (digital output)
- **Current-limiting resistor:** 1k ohm in series between GP16 and SSR control input
- **Safety fuse:** RY85 85degC one-time thermal fuse in series on AC output side
  (hardware-only safety, no firmware involvement)
- **Load:** 500W ceramic PTC heater

---

## Class Interface

```python
class Heater:
    def __init__(self, pin: int, logger=None):
        ...
```

### Constructor

- `pin` -- GPIO pin number (caller passes GP16)
- `logger` -- optional Logger instance; if None, no logging occurs
- Initialise the pin as a digital output, driven LOW at construction
- Log an event on construction: `"Heater initialised, SSR off"`

### Methods

```python
def on(self) -> None:
    """Drive SSR control input HIGH, turning heater on."""

def off(self) -> None:
    """Drive SSR control input LOW, turning heater off."""

def is_on(self) -> bool:
    """Return True if heater is currently commanded on."""
```

---

## Behaviour

### on()
- Drive GP16 HIGH
- Update internal state to reflect heater is on
- Log event: `"Heater on"` at level INFO
- No return value

### off()
- Drive GP16 LOW
- Update internal state to reflect heater is off
- Log event: `"Heater off"` at level INFO
- No return value

### is_on()
- Return internal state bool -- reflects last commanded state
- Does not read GPIO; tracks state in software

---

## Logging

Follows the same pattern as all other modules:

```python
if self._logger:
    self._logger.event("heater", "Heater on")
```

Source string: `"heater"`

Events to log:
- Construction: `"Heater initialised, SSR off"` at INFO
- `on()`: `"Heater on"` at INFO
- `off()`: `"Heater off"` at INFO

---

## Boot Safety

The SSR control pin must be driven LOW at construction before any other
initialisation. This ensures the heater cannot fire due to a floating GPIO
during boot. This mirrors the pattern used in exhaust.py for the MOSFET gate.

---

## Unit Tests

Provide a standalone test file `test_heater.py` at the repo root following
the hardware-in-the-loop pattern used by other modules.

Tests should cover:

1. **Heater initialises off** -- after construction, `is_on()` returns False
   and SSR pin is LOW
2. **on() turns heater on** -- `is_on()` returns True after `on()`
3. **off() turns heater off** -- `is_on()` returns False after `on()` then `off()`
4. **Double on() is safe** -- calling `on()` twice does not error
5. **Double off() is safe** -- calling `off()` twice does not error
6. **Logger receives on event** -- verify logger.event() called with correct
   source and message on `on()`
7. **Logger receives off event** -- verify logger.event() called with correct
   source and message on `off()`
8. **Logger=None is safe** -- all methods work without logger

---

## Notes

- No current monitoring -- the SSR switches 120V AC; the INA219 monitors DC rails
  only and will not see heater load current
- No duty cycling or PWM -- on/off only; temperature control is the
  responsibility of the drying schedule controller in main.py
- No safety interlock logic in this module -- that is handled at the controller
  level and by the physical RY85 thermal fuse
- ASCII only in all strings -- no Unicode characters in comments, docstrings,
  log messages, or print statements

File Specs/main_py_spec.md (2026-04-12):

# MAIN_PY_SPEC.md

Spec for `main.py` -- the entry point for the Pico 2W kiln controller firmware.
This is the top-level module that wires all `lib/` modules together, starts the
WiFi AP, runs the HTTP REST API server, and executes the control loop.

---

## Overview

`main.py` runs at boot. It:

1. Initialises all hardware modules in safe order
2. Starts the WiFi Access Point
3. Launches the asyncio HTTP server (REST API)
4. Runs the `KilnSchedule.tick()` control loop
5. Handles uncaught exceptions with a safe shutdown and reboot

The HTTP server and the control loop run concurrently as asyncio tasks. The
control loop must never be blocked by HTTP handler execution.

---

## Files

| File | Action |
|---|---|
| `main.py` | Create at repo root |
| `config.py` | Create at repo root (see template below) |
| `calibration.json` | Created at runtime by `/calibration` POST endpoint |

---

## Module Instantiation Order

Order matters. Hardware is driven to a safe state at each constructor. Follow
this sequence exactly:

```python
# 1. SD card first -- logger depends on it
sdcard = SDCard(...)

# 2. Logger -- all modules may accept logger after this point
logger = Logger(sdcard)

# 3. Shared I2C bus (SHT31 sensors + INA219 current monitors)
i2c0 = machine.I2C(0, sda=machine.Pin(0), scl=machine.Pin(1), freq=100_000)

# 4. Sensors (I2C0, shared bus)
sensors = SHT31Sensors(i2c=i2c0, logger=logger)

# 5. Current monitors (I2C0, same bus)
monitor_12v = CurrentMonitor(i2c0, 0x40, "12V", logger=logger)
monitor_5v  = CurrentMonitor(i2c0, 0x41, "5V",  logger=logger)

# 6. Circulation fans
circulation = CirculationFans(pwm_pin=18, gate_pin=19,
                               current_monitor=monitor_12v, logger=logger)

# 7. Exhaust fan
exhaust = ExhaustFan(pwm_pin=17, gate_pin=21, tach_pin=22, logger=logger)

# 8. Vents
vents = Vents(intake_pin=14, exhaust_pin=15, logger=logger)

# 9. Heater
heater = Heater(pin=16, logger=logger)

# 10. Moisture probes -- load calibration offsets from SD if available
moisture = MoistureProbe(
    ch1_excite=6, ch1_adc=26,
    ch2_excite=7, ch2_adc=27,
    logger=logger
)
_load_calibration(moisture, sdcard)    # see Calibration Loading section

# 11. Display
display = KilnDisplay(uart_id=1, tx_pin=8, rx_pin=9,
                       button_pin=20, logger=logger)

# 12. LoRa (mock or real depending on config.USE_MOCK_LORA)
if config.USE_MOCK_LORA:
    lora = LoRaMock(logger=logger)
else:
    lora = LoRa(spi_id=1, sck=10, mosi=11, miso=12, cs=13,
                rst=28, logger=logger)

# 13. Schedule controller -- depends on all above
schedule = KilnSchedule(
    sdcard=sdcard, sensors=sensors, moisture=moisture,
    heater=heater, exhaust=exhaust, circulation=circulation,
    vents=vents, lora=lora, logger=logger
)
```

**I2C sharing:** `SHT31Sensors` accepts an optional `i2c` parameter. When
provided, it uses the shared bus directly instead of creating its own.
`CurrentMonitor` also accepts an external `i2c` instance. Both refactors
are complete -- see instantiation order above for the shared `i2c0` pattern.

---

## Boot Sequence

```
1. Import all modules
2. Print boot banner to REPL (firmware version, board)
3. Instantiate all hardware modules (order above)
4. Start WiFi AP (SSID and password from config.py)
5. Log boot event: logger.event("main", "Boot complete. AP started.")
6. Register display pages (see Display Pages section)
7. Start asyncio event loop:
   a. Task: HTTP server (port 80)
   b. Task: control loop (calls schedule.tick() + display.tick())
   c. Task: LoRa keepalive heartbeat (if no active run)
8. Run loop forever; handle KeyboardInterrupt gracefully
```

---

## WiFi AP

```python
import network

ap = network.WLAN(network.AP_IF)
ap.config(ssid=config.AP_SSID, password=config.AP_PASSWORD,
          security=network.WPA2 if config.AP_PASSWORD else 0)
ap.active(True)

# Wait for AP to become active (poll ap.active() with 100ms delay, max 5s)
# Log AP IP address once active
```

AP IP is always `192.168.4.1` by default on MicroPython.

---

## Control Loop

The control loop runs as an asyncio task. It:

1. Calls `schedule.tick()` at the interval returned by
   `schedule.tick_interval_s` (30s when venting, 120s otherwise)
2. Calls `display.tick()` every 100ms (button debounce, timeout, page refresh)
3. Updates the cached `/status` response (module-level dict) after each tick

```python
async def control_loop():
    while True:
        schedule.tick()
        _update_status_cache()
        await asyncio.sleep(schedule.tick_interval_s)

async def display_loop():
    while True:
        display.tick()
        await asyncio.sleep(0.1)
```

The `_update_status_cache()` function reads `schedule.status()` and stores the
result in a module-level dict. All `/status` HTTP responses read from this cache
-- they do not call `schedule.status()` directly, avoiding any timing conflict.

---

## HTTP Server

Use MicroPython `asyncio` streams to implement a minimal HTTP/1.1 server.
Do not use any third-party HTTP framework.

```python
async def http_server():
    server = await asyncio.start_server(handle_request, "0.0.0.0", 80)
    async with server:
        await server.serve_forever()
```

**Request routing:**

Implement a simple router that maps `(method, path_prefix)` tuples to handler
coroutines. Path parameters (e.g. `/schedules/{filename}`) are extracted by
string splitting.

**Authentication:**

Every handler (except `/health`) checks for the `X-Kiln-Key` header before
processing. If missing or wrong, return 401 immediately.

**Response helpers:**

```python
def json_response(writer, data, status=200):
    body = json.dumps(data)
    writer.write(f"HTTP/1.1 {status} OK\r\n"
                 f"Content-Type: application/json\r\n"
                 f"Content-Length: {len(body)}\r\n"
                 f"\r\n{body}")
```

---

## RTC Sync

On `POST /time`, set the Pico RTC:

```python
import machine
rtc = machine.RTC()

def set_rtc(unix_ts):
    # Convert Unix timestamp to (year, month, day, weekday, hour, min, sec, subsec)
    import utime
    t = utime.localtime(unix_ts)
    rtc.datetime((t[0], t[1], t[2], t[6], t[3], t[4], t[5], 0))
```

Auto-sync: the first app connection triggers a `/time` POST automatically when
the app's "Auto-sync on connect" setting is enabled and the `/health` response
shows `rtc_set: false`.

---

## Calibration Loading

At boot, after `MoistureProbe` is instantiated, attempt to load
`calibration.json` from the SD card:

```python
def _load_calibration(moisture_probe, sdcard):
    text = sdcard.read_text("calibration.json")
    if text is None:
        return    # no file -- factory defaults (0.0 offset)
    try:
        cal = json.loads(text)
        moisture_probe.set_calibration(
            channel_1_offset=cal.get("channel_1_offset", 0.0),
            channel_2_offset=cal.get("channel_2_offset", 0.0)
        )
    except Exception as e:
        logger.event("main", f"Calibration load failed: {e}", level="WARNING")
```

`MoistureProbe.set_calibration(channel_1_offset, channel_2_offset)` is a new
method to be added to `lib/moisture.py` as part of this work.

The `calibration.json` format:

```json
{
  "channel_1_offset": -1.2,
  "channel_2_offset": -0.8,
  "calibrated_at": 1711900000
}
```

Corrected MC% = raw MC% + offset (offset may be negative or positive).

---

## Display Pages

Register the following pages on the `KilnDisplay` instance:

```python
display.register_page("status",   render_status_page)
display.register_page("sensors",  render_sensors_page)
display.register_page("moisture", render_moisture_page)
display.register_page("system",   render_system_page)
```

Page render functions read from the cached status dict and use `display` drawing
primitives to render the page. They are called by `display.tick()` when the page
changes or the display wakes from timeout.

**Page 1 -- Status:**
- Stage name + number
- Stage type
- Stage elapsed hours
- Heater / vent / fan state indicators

**Page 2 -- Sensors:**
- Lumber temp + RH (actual vs target)
- Intake temp + RH

**Page 3 -- Moisture:**
- Channel 1 MC% + resistance
- Channel 2 MC% + resistance
- Target MC% for current stage

**Page 4 -- System:**
- 12V rail current (mA)
- 5V rail current (mA)
- Uptime
- SD card mounted indicator
- LoRa TX count

---

## LoRa Heartbeat

When no run is active, transmit a heartbeat packet every 5 minutes so the Pi4
daemon can confirm the Pico is alive and the link is up.

```python
async def lora_heartbeat():
    while True:
        if not schedule._running:
            lora.send_telemetry({
                "type": "heartbeat",
                "ts": utime.time(),
                "uptime_s": utime.ticks_ms() // 1000,
                "run_active": False
            })
        await asyncio.sleep(300)
```

The Pi4 daemon records heartbeat packets in the `telemetry` table with
`run_id = NULL`.

---

## System Test Implementation

The system test suite runs as an asyncio task started by `POST /test/run`.
Results are stored in a module-level list that `/test/status` reads.

Test definitions are in a list of `(id, name, group, test_fn)` tuples where
`test_fn` is a coroutine that returns `(status, detail)`.

**Test list:**

Unit Tests (per module):
- `exhaust_init` -- ExhaustFan: fan starts at 50%, RPM > 0, stops cleanly
- `exhaust_tach` -- ExhaustFan: tach reads non-zero RPM at 75%
- `circulation_init` -- CirculationFans: starts at 20% minimum, no current fault
- `vents_open_close` -- Vents: open, verify servo moved, close
- `heater_on_off` -- Heater: on, verify GPIO high, off, verify GPIO low
- `sdcard_mount` -- SDCard: mounts successfully, listdir returns a list
- `sensors_read` -- SHT31Sensors: both sensors return plausible temp/RH values
- `moisture_read` -- MoistureProbe: both channels return resistance values
- `current_12v` -- CurrentMonitor 0x40: returns non-zero mA reading
- `current_5v` -- CurrentMonitor 0x41: returns non-zero mA reading
- `display_init` -- KilnDisplay: clear and draw text without exception
- `lora_mock_tx` -- LoRa: send_telemetry returns True; if mock, note in detail

Integration Tests:
- `schedule_load` -- KilnSchedule: loads maple_1in.json successfully
- `logger_event` -- Logger: writes an event to SD card, reads it back
- `logger_data` -- Logger: writes a data row, reads it back

Commissioning Tests:
- `heater_temp_rise` -- Heater on for 90s; temp_lumber rises >= HEATER_FAULT_RISE_C;
  heater off. SKIP if temp_lumber already > 50C (too hot to test safely).
- `lora_tx_real` -- Send a real LoRa packet; SKIP if config.USE_MOCK_LORA is True
- `rtc_set` -- RTC year >= 2024; FAIL with "Sync clock via app" if not set

All tests must leave hardware in a safe state on completion (heater off, fans off
or at idle, vents closed).

---

## Exception Handling and Watchdog

Wrap the main asyncio entry point in a try/except:

```python
try:
    asyncio.run(main())
except Exception as e:
    # Safe shutdown
    heater.off()
    vents.open()      # fail-open for ventilation
    circulation.off()
    exhaust.off()
    logger.event("main", f"Fatal exception: {e}", level="ERROR")
    import machine
    machine.reset()   # reboot after 5 seconds
```

A MicroPython software watchdog timer (WDT) may be added in a later iteration.
For now, the asyncio loop itself is the liveness mechanism.

---

## config.py Template

```python
# config.py -- deploy to Pico root

VERSION          = "1.0.0"

# WiFi AP
AP_SSID          = "KilnController"
AP_PASSWORD      = "changeme"      # WPA2; empty string for open AP

# REST API
API_KEY          = "changeme"      # must match Kivy app Settings

# LoRa
USE_MOCK_LORA    = True            # set False when Ra-02 hardware is installed
LORA_SF          = 9
LORA_FREQ_MHZ    = 433.0

# Schedule
DEFAULT_SCHEDULE = "maple_1in.json"

# Display
DISPLAY_TIMEOUT_S = 30             # seconds before backlight off; 0 to disable

# Logging
LOG_FLUSH_INTERVAL_S = 120         # seconds between forced SD flushes
```

---

## Constraints and Patterns

- **ASCII only.** No Unicode in any string, comment, or docstring.
- **asyncio throughout.** No `time.sleep()` in any task -- use
  `await asyncio.sleep()`. Blocking the event loop blocks the HTTP server.
- **No global mutable state except status cache.** The status cache dict is the
  only module-level mutable state intentionally shared between tasks.
- **Safe boot state.** All hardware modules drive outputs to safe state in their
  constructors. `main.py` must not assume any GPIO state from a previous run.
- **Silent SD failures.** SD card errors must never crash the control loop.
  All SD reads/writes are wrapped in try/except.
- **Follow exhaust.py patterns.** Class-based modules, logger dependency injection,
  no direct hardware imports in main.py beyond `machine` and `network`.
- **No third-party libraries.** Standard MicroPython + existing `lib/` modules only.

---

## Open Items and Prerequisites

Before `main.py` can be fully implemented, the following prerequisite changes
are required in existing modules:

1. ~~**SHT31Sensors I2C refactor:**~~ DONE. Accepts optional `i2c` parameter;
   falls back to creating its own if not provided.

2. ~~**CurrentMonitor I2C refactor:**~~ DONE. Already accepted external `i2c`
   instance at initial implementation.

3. ~~**MoistureProbe.set_calibration():**~~ DONE. Applies per-channel MC% offsets;
   corrected MC% = raw MC% + offset. Offsets default to 0.0.

4. **Real lib/lora.py:** Replace mock with SX1278 register implementation once
   Ra-02 hardware arrives. Same interface as mock; `is_mock` returns False.

5. **lib/schedule.py status() field alignment:** Ensure `status()` return dict
   keys match the field names in the Pico REST API `/status` response exactly
   (including `mc_channel_1`, `mc_channel_2`, `current_12v_ma`, `current_5v_ma`).

Prerequisites 1-3 are complete. `main.py` implementation can proceed.

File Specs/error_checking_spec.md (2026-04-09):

# Error Checking and Fault Surfacing Spec

Author: Steve, drafted via Claude Code session 2026-04-08
Status: Draft - intended as input for a future Claude Code session that will
implement the changes outlined here.

---

## Why this spec exists

The kiln firmware modules in `lib/` already detect a number of faults at
runtime - I2C errors, current out of range, sensor CRC failures, fan stalls,
LoRa init failures, SD write failures, etc. Each module logs these to the SD
event log and (in some cases) to the REPL. **But there is no consistent path
from "module detected a fault" to "operator sees the fault on the Kivy app."**

The motivating example: during a recent test the circulation fans were
loose, drew only 35 mA instead of the expected 200-500 mA range, and
`circulation.verify_running()` correctly logged an ERROR. The Kivy dashboard
showed nothing - no banner, no badge, nothing. The operator only noticed
because the fans weren't spinning. That is exactly the failure mode the fault
banner is supposed to catch.

This spec defines:

1. A consistent **fault model** every `lib/` module exposes (the "fault
   contract").
2. A central **fault aggregator** that polls every module each control-loop
   tick and produces a single list of active faults.
3. The **transport** that surfaces those faults to the Kivy app via the
   `/status` REST endpoint.
4. A **mapping rule** ("anything that causes a unit test to fail must also
   be checked at runtime") and the asymmetries we need to fix to satisfy it.
5. A migration order so the work can be done module-by-module without
   breaking the existing firmware.

---

## Background: today's behaviour

| Module | Fault detection at runtime | Surfaced via | Polled by main.py? |
|---|---|---|---|
| `circulation.py` | `verify_running()` checks 12V current after `on()` | Logs ERROR; returns True/False/None | No - result discarded |
| `exhaust.py` | None at runtime (test() checks RPM, production does not) | n/a | No |
| `vents.py` | `verify_position()` checks 5V current at mid-travel | Logs WARN; returns True/False/None | No - schedule.py never calls it |
| `heater.py` | None | n/a | n/a |
| `SHT31sensors.py` | I2C / CRC failures, returns None | Logs WARNING per failure | Detected indirectly via None reads in schedule cache |
| `moisture.py` | Probe disconnect / out of range, returns None | Logs WARNING per failure | Same |
| `current.py` | I2C read failure, init failure, `check_range()` | Logs ERROR / WARN; `_ready` flag (private) | No (only init-time check) |
| `lora.py` | Init failure, TX timeout, payload errors | Logs ERROR / WARNING; `is_initialised` property | At init only |
| `sdcard.py` | Mount failure, listdir/read failure | Logs WARNING; `is_mounted()` property | Init only |
| `logger.py` | SD mount failure, file open / write failure | Logs WARNING; silently drops writes after first failure | No |
| `schedule.py` | Heater timeout, temp/RH out-of-range, sensor read failure | Logs + sends LoRa alert; populates `_last_alert_ts` | **Yes - this is the only path that ends up in `active_alerts`** |
| `display.py` | UART timeout (no "OK") | Returns empty string; no logging | No |

`main.py`'s `_update_status_cache()` builds the `/status` payload's
`active_alerts` field **only** from `schedule._last_alert_ts`. Faults in
every other module are completely invisible to the Kivy app, even though they
are written to the SD event log.

The Kivy dashboard's fault banner is wired to `active_alerts`, so the gap is:

> **Detected but not propagated** - the firmware sees the fault, writes it
> to the SD card, and then forgets about it.

---

## Three-tier alert model

Not every interesting event is a "fault." A drying stage that ran out of
time without hitting its MC target is a real concern that the operator must
see, but no hardware is broken - the kiln is healthy and the *batch* may
not be. Treating that the same way as "the circulation fans aren't
spinning" trains the operator to ignore the red banner.

Three tiers, each with its own UI treatment:

| Tier | Examples | What it means | Dashboard treatment |
|---|---|---|---|
| **FAULT** | `CIRC_FAN_FAULT`, `SENSOR_LUMBER_FAIL`, `SD_WRITE_FAIL`, `HEATER_TIMEOUT`, `LORA_FAIL` | Hardware/firmware misbehaving. Operator may need to inspect or fix the kiln. | Red banner. Always elevated. |
| **NOTICE** | `STAGE_GOAL_NOT_MET`, `WATER_PAN_REMINDER` | Procedural / batch issue. The kiln is healthy; the schedule needs the operator's attention. | Amber banner. Elevated but distinct from a hardware fault. |
| **INFO** | `stage_advance`, `equalizing_start`, `conditioning_start`, `run_complete` | Lifecycle log entry. Useful in the audit trail; should never interrupt the operator. | No banner on the dashboard. Visible on the Alerts screen only. |

### Today's gap

The firmware does not currently distinguish these tiers. Every code that
flows through `schedule._last_alert_ts` is treated identically, and
`/status` returns one undifferentiated `active_alerts: list[str]` that
includes informational lifecycle events alongside genuine faults.

The Kivy app currently works around this with a hardcoded classification
table in `kilnapp/alerts.py` that maps each known code to a tier. This is
a stopgap. The Kivy table will drift out of sync with the firmware as new
alert codes are added.

### Firmware tagging requirement

Every alert / fault code emitted by the firmware MUST declare its tier at
the source. Two acceptable shapes:

**Shape A: severity field on each alert.** `_status_cache["fault_details"]`
becomes a list of `{code, source, message, tier}` dicts where `tier` is
one of `"fault"`, `"notice"`, `"info"`. The Kivy app classifies by reading
`tier` directly. `active_alerts` continues as a flat list of codes for
backwards compatibility but is augmented by `fault_details`.

**Shape B: per-tier arrays.** `/status` returns three explicit arrays:
`faults: list[str]`, `notices: list[str]`, `infos: list[str]`. Simple to
consume but breaks the existing `active_alerts` field. Pi4 daemon and
LoRa packet must be updated in lockstep.

**Recommendation: Shape A.** It is additive (no client breakage), it
matches the existing `fault_details` field this spec already proposes, and
it lets a single code change tier in the future without a flag day.

### Existing client-side classification table

The Kivy app's [`KivyApp/kilnapp/alerts.py`](../KivyApp/kilnapp/alerts.py)
already enumerates every alert code the system is known to emit, organised
into `FAULT_CODES` and `NOTICE_CODES` frozensets. **That file is the
authoritative starting list of codes for the firmware author** - rather
than re-deriving the codes from scratch, copy the two sets and assign each
code its tier in the firmware module that emits it. Anything not in either
set is INFO by default.

Codes the Kivy table currently knows about:
- **FAULT**: `CIRC_FAN_FAULT`, `EXHAUST_FAN_STALL`, `VENT_STALL`,
  `SENSOR_LUMBER_FAIL`, `SENSOR_INTAKE_FAIL`, `SENSOR_FAILURE`,
  `MOISTURE_PROBE_FAIL`, `HEATER_TIMEOUT`, `HEATER_FAULT`, `TEMP_OOR`,
  `RH_OOR`, `TEMP_OUT_OF_RANGE`, `RH_OUT_OF_RANGE`, `OVER_TEMP`,
  `SD_FAIL`, `SD_WRITE_FAIL`, `LORA_FAIL`, `LORA_TIMEOUT`
- **NOTICE**: `STAGE_GOAL_NOT_MET`, `STAGE_GOAL_NOT_REACHED`,
  `WATER_PAN_REMINDER`

### Per-module tier assignment

The migration plan section lower in this spec must be updated so each
module's `fault_code` is accompanied by an explicit tier. Modules
implementing the fault contract should expose:

```python
class SomeModule:
    fault: bool
    fault_code: Optional[str]
    fault_message: Optional[str]
    fault_tier: str  # "fault" | "notice" | "info" - default "fault"
    fault_last_checked_ms: Optional[int]
```

Hardware modules (circulation, exhaust, vents, sensors, moisture, current,
lora, sdcard, logger, display) all default to `fault_tier = "fault"` -
their entire purpose is to detect hardware problems, so anything they
flag is hardware. The schedule module is the only place that emits NOTICE
codes (`STAGE_GOAL_NOT_MET`, `WATER_PAN_REMINDER`) and the only place
that emits INFO codes (`stage_advance`, etc.). Schedule alerts should
carry the tier explicitly when they are recorded in `_last_alert_ts`.

### Tier must propagate to /alerts as well

The Kivy Alerts screen ([`KivyApp/kilnapp/screens/alerts.py`](../KivyApp/kilnapp/screens/alerts.py))
currently calls `kilnapp.alerts.classify(code)` on every row returned by
`GET /alerts` because the response rows have no tier field. Once the
firmware tags severity at source, **`/alerts` rows must include a `tier`
field** (one of `"fault"` / `"notice"` / `"info"`) so the screen can
drop its client-side classification call.

Concretely the new `/alerts` row shape becomes:

```json
{
  "ts": 1712685000,
  "level": "WARN",
  "tier": "fault",
  "source": "circulation",
  "message": "Current out of range after on() - possible fan fault",
  "code": "CIRC_FAN_FAULT"
}
```

The Pico stores raw event log lines today, so the implementer has a
choice: either embed the tier in the log line format itself
(`2026-04-09 14:32:01 [ERROR] [circulation] [FAULT] CIRC_FAN_FAULT: ...`)
and update `_parse_event_line` in `main.py` to extract it, or keep the
log format and look up the tier from a static table when serving
`/alerts`. The former survives a Pico reboot; the latter is simpler.

### Acceptance criterion (additional)

Once the firmware tags severity, the Kivy app should drop the
`FAULT_CODES` / `NOTICE_CODES` tables in `kilnapp/alerts.py` and the
`classify()` calls in `kilnapp/screens/alerts.py` and read `tier` from
`fault_details` (on `/status`) and from each `/alerts` row directly. The
hardcoded tables remain only as a backwards-compatibility fallback for
older firmware.

---

## The rule we want to satisfy

> **Anything that causes a unit test to fail should also be checked at
> runtime, and any fault detected at runtime must be visible in the
> `/status` `active_alerts` array within one control-loop tick.**

This is a two-part rule and both halves matter:

- **Test/production parity** - if `test()` asserts that
  `circulation.verify_running()` returns True, then production must call
  `verify_running()` and react when it returns False. Today the production
  call discards the return value.
- **Operator visibility** - faults must end up in `active_alerts` so the
  Kivy fault banner lights up. The operator should never have to SSH into
  the Pico and grep the SD log to find out something is wrong.

---

## The fault contract

Every hardware module in `lib/` (circulation, exhaust, vents, heater,
sensors, moisture, current, lora, sdcard, logger, display) gains the same
small set of fault-related members. Modules are still free to implement
their own internal checks; this contract just provides a consistent way for
`main.py` to ask "are you broken right now?"

### Required public surface

```python
class SomeModule:
    # Boolean: is there an unresolved fault on this module right now?
    # Set by the module when a check fails; cleared when a successful
    # check brings it back into spec.
    fault: bool

    # Short stable code suitable for use in active_alerts (UPPER_SNAKE).
    # Examples: "CIRC_FAN_FAULT", "SENSOR_LUMBER_FAIL", "SD_WRITE_FAIL".
    # None when fault is False.
    fault_code: Optional[str]

    # Short human-readable message; surfaces in the Kivy fault banner
    # tooltip and logs. None when fault is False.
    fault_message: Optional[str]

    # Optional: the last time the module performed its self-check, so
    # the aggregator can detect a stuck module that hasn't been polled.
    # time.ticks_ms() value, or None if never checked.
    fault_last_checked_ms: Optional[int]

    def check_health(self) -> bool:
        """Run any cheap self-checks the module supports and update
        fault / fault_code / fault_message / fault_last_checked_ms.
        Returns the new value of `fault` (True == something is wrong).

        Modules may also update fault state from inside their normal
        operations - e.g. circulation.on() should set fault = True
        immediately if verify_running() fails. check_health() is for
        the periodic 'is everything still OK' poll between commands.
        """
```

### Latching vs. clearing

- A fault is **latched** as soon as it is observed.
- It is **cleared** when:
  - A successful subsequent check brings the value back into spec, AND
  - The module decides the underlying cause is plausibly resolved (e.g.
    `circulation.off()` clears `CIRC_FAN_FAULT` because we're no longer
    expecting current draw).
- Modules MUST NOT auto-clear faults on a single successful read if the
  underlying mechanism is flaky - require N consecutive good reads before
  clearing. (Recommendation: N = 3.)

### Multiple faults per module

Most modules will only ever have one active fault at a time. For modules
that legitimately have multiple independent failure modes (e.g. SHT31 has
two sensors at different addresses), use one of:

- Two boolean fields: `fault_lumber`, `fault_intake` and a derived
  `fault = fault_lumber or fault_intake`. `fault_code` returns whichever
  is active (or a combined code if both).
- A single fault but with `fault_code` distinguishing them
  (`SENSOR_LUMBER_FAIL` vs `SENSOR_INTAKE_FAIL`).

The choice is per-module. Be consistent within a module.

---

## The aggregator

`main.py` (or a new `lib/health.py` module) implements the central
aggregator. It runs inside `_update_status_cache()` so the cache rebuilt
on every control-loop tick (10s while idle, 30-120s during a run) carries
fresh fault state.

### Normative requirements

1. **Skip absent modules.** Some `lib/` modules legitimately fail to
   construct at boot (e.g. SD card not present, INA219 missing, display
   not wired). The aggregator MUST check `if mod is None: continue` for
   every module before calling `check_health()`. The current
   `_status_cache` builder already follows this pattern (`if monitor_12v
   is not None`, `if circulation else 0`, etc.); the aggregator must
   match.

2. **Catch exceptions from `check_health()`.** A buggy module must not
   crash the status cache update. Wrap each `check_health()` call in a
   try/except and surface the failure as a synthetic
   `MODULE_CHECK_FAILED` fault tagged with the module name.

3. **Run during idle, not just during runs.** `_update_status_cache()`
   has an "idle direct reads" block (added recently to keep
   sensor / moisture values fresh on the dashboard when no run is
   active). The aggregator MUST run inside that block too, in both the
   run-active and idle code paths. Otherwise faults won't appear on the
   Kivy dashboard until the next run starts - which defeats the whole
   point for the "is the kiln OK before I start a run" check.

4. **Cheap calls only.** `check_health()` runs every cache update, so
   it must not perform any expensive operation: no I2C reads on every
   call, no SD writes, no SPI transactions just to ask "are you OK".
   Modules that need active probing should perform it in their own
   `tick()` method or alongside their normal operations and only
   re-read cached state from `check_health()`.

### Sketch

```python
# In _update_status_cache(), after the existing schedule alert collection:

faults = []  # list of (code, source, message)

for source, mod in [
    ("circulation", circulation),
    ("exhaust", exhaust),
    ("vents", vents),
    ("heater", heater),
    ("sensors", sensors),
    ("moisture", moisture),
    ("current_12v", monitor_12v),
    ("current_5v", monitor_5v),
    ("lora", lora),
    ("sdcard", sdcard),
    ("logger", logger),
    ("display", display),
]:
    if mod is None:
        continue
    try:
        # Cheap re-check. Do NOT do anything expensive here - this runs
        # every status cache update.
        mod.check_health()
    except Exception as e:
        faults.append(("MODULE_CHECK_FAILED", source, str(e)))
        continue
    if getattr(mod, "fault", False):
        faults.append((
            mod.fault_code or "UNKNOWN_FAULT",
            source,
            mod.fault_message or "",
        ))

# Existing schedule alerts continue to flow in via _last_alert_ts.
for atype in active_alerts:
    faults.append((atype.upper(), "schedule", ""))

# Deduplicate by code (highest source priority wins) and serialise.
_status_cache["active_alerts"] = [code for code, _src, _msg in faults]
_status_cache["fault_details"] = [
    {"code": code, "source": src, "message": msg}
    for code, src, msg in faults
]
```

### Two new `/status` fields

- `active_alerts: list[str]` - already exists, change semantics so it
  contains every fault from every source, not just schedule alerts.
  Backwards-compatible with the Kivy dashboard's existing fault banner.
- `fault_details: list[{code, source, message, tier}]` - new. Powers the
  Alerts screen (Phase 5, already shipped) and the dashboard's fault
  banner with rich per-fault info.

Update `Specs/lora_telemetry_spec.md` and the Pi4 daemon to mirror these
field changes.

### LoRa wire format constraints

The LoRa telemetry packet has a hard 255-byte cap (SX1278 FIFO) and the
existing telemetry payload is already ~225 bytes after the recent
compaction work in `main.py:_build_compact_json` (see `PROJECT.md` "Known
firmware bugs" for the history). There is **no room** to embed
`fault_details` as a list of `{code, source, message, tier}` dicts in
every telemetry packet.

Recommendation: send only a flat list of fault codes over LoRa, and
serve the rich `fault_details` exclusively over the HTTP `/status`
endpoint. The Pi4 daemon receives the LoRa codes, looks up the message
text from a static table (or just displays the code), and exposes the
fuller `fault_details` shape via its own `/status` endpoint.

```python
# In _build_compact_json for the LoRa packet, add a single short field:
#   "faults": ["CIRC_FAN_FAULT", "SD_WRITE_FAIL"]
# Sized check: each code is ~15-20 chars, list overhead ~5 chars per
# entry. Three faults adds ~70 bytes. The aggregator MUST cap the LoRa
# fault list to (e.g.) 5 codes to keep us safely under 255.
```

Anything new added to the LoRa packet must use the same conventions as
the existing fields:
- Hand-built compact JSON via `_compact_json_value` / `_build_compact_json`,
  not `json.dumps`. MicroPython serialises floats at full IEEE754
  precision and inserts whitespace after every separator.
- Short stable field names (`faults`, not `active_fault_codes`).
- Floats rounded to 1dp.
- No nested objects per fault. Lists of strings are fine.

---

## Test/production parity gaps to close

These are the places where the unit test asserts something the production
code does not. The aggregator above only works once these are fixed.

| Module | Test asserts | Production does | Fix |
|---|---|---|---|
| `circulation.py` | `verify_running()` returns True after `on()` | Calls it but discards result | Latch `fault = True` inside `verify_running()` when current is out of range |
| `exhaust.py` | RPM > 0 within tach sample window | Reads RPM only on demand from main.py for telemetry | Add `verify_running()` similar to circulation, latch `fault` if RPM == 0 after spin-up |
| `vents.py` | `verify_position()` returns True after each `_move()` | `_move()` samples current but never calls verify_position from production | Have `_move()` call verify_position() itself and latch `fault` + `fault_code = "VENT_STALL"` |
| `SHT31sensors.py` | Both sensors return non-None | Returns None silently | Track per-sensor fail count; latch `fault` after 3 consecutive failures |
| `moisture.py` | Both channels return numeric MC | Returns None silently | Same: 3-consecutive-failure latch |
| `current.py` | `_ready` is True | Init failure logged but not exposed | Promote `_ready` to public `fault` property |
| `lora.py` | `is_initialised` is True after init | Already exposed but not aggregated | Add `fault` alias + aggregator entry |
| `sdcard.py` | `is_mounted()` is True | Already exposed but not aggregated | Add `fault` alias + aggregator entry |
| `logger.py` | Each `event()` and `data()` call writes | After first failure, writes silently drop | Track `_write_failures`; latch `fault` after 3 consecutive failures |
| `display.py` | Each command returns "OK" | UART timeouts return empty string, never escalate | Track consecutive timeouts; latch `fault` after N |
| `schedule.py` | n/a (no unit test) | Already populates `_last_alert_ts` | Continue to flow into the aggregator unchanged |

`heater.py` has no failure modes the firmware can detect; safety lives in
the RY85 thermal fuse. It still implements the contract (always
`fault = False`) so the aggregator's loop is uniform.

---

## Migration plan

Done in this order so each step is independently testable on the bench:

1. **Define the contract.** Add a tiny `lib/fault.py` (or just put the
   four properties + `check_health()` stub directly in each module) so
   the contract is real Python and not just docs.

2. **Migrate one module end-to-end as a reference.** Recommended:
   `circulation.py`. It has the clearest existing check (`verify_running`),
   the example failure that prompted this spec, and a small surface area.
   Update its tests too. After this step:
   - `circulation.fault` becomes True when current is out of range.
   - `_update_status_cache()` polls it.
   - `active_alerts` contains `"CIRC_FAN_FAULT"`.
   - The Kivy fault banner lights up. Verify on the bench.

3. **Migrate the easy modules.** `current.py`, `sdcard.py`, `lora.py`,
   `heater.py` - each is small and most already have the underlying
   detection in place.

4. **Migrate the sensor / moisture modules** with the consecutive-failure
   counter. Be careful not to flap on transient I2C glitches.

5. **Migrate `vents.py` and `exhaust.py`** which need new runtime checks
   that did not exist before (only test() did them).

6. **Migrate `logger.py` and `display.py`** which need write/UART failure
   counters.

7. **Update the aggregator in `main.py`** to walk all modules.

8. **Update `Specs/lora_telemetry_spec.md`** to add `fault_details` to
   the LoRa telemetry packet so cottage-mode users see the same info.  Add a ToDo in PROJECT.md to implement the updated telemetry spec and for the Pi4 daemon spec to mirror the new fields.

9. **Update the Kivy app**:
   - Phase 5 Alerts screen will consume `fault_details`.
   - Dashboard's existing `FaultBanner` already consumes `active_alerts`
     so no change needed there.

Each step can be merged independently. After steps 1-2 the system already
catches the original circulation-fan-fault scenario.

---

## Out of scope for this spec

- **Fault history.** Faults that have come and gone. The SD event log
  already records these; the Alerts screen will fetch them from the
  log on demand.
- **Recovery / retry.** Some faults benefit from a retry policy
  (SD mount in particular). That belongs in a separate "self-healing"
  spec, not this one.
- **Push notifications.** The Pi4 daemon pushes to ntfy.sh. Once
  `fault_details` is in the LoRa packet the daemon already has what it
  needs.
- **Severity grading.** This spec treats all faults as equally important.
  A future revision should add `severity = INFO | WARNING | ERROR` so the
  Kivy dashboard can choose between an amber pill and a red banner.

---

## Acceptance criteria

A future Claude Code session has finished this work when:

1. Every module in `lib/` exposes the four required properties and a
   `check_health()` method.
2. `main.py`'s `_update_status_cache()` calls `check_health()` on every
   module each tick, in both the run-active and idle code paths.
3. **Canonical motivating example - circulation fan disconnect.** With
   the circulation fan power harness physically disconnected (or one of
   the fan blades blocked so it can't spin), start the `test_quick.json`
   schedule from the Kivy dashboard. Wait one control-loop tick (~10
   seconds while idle, the first tick of the run otherwise). The
   following must all hold:

   `GET /status` returns:
   ```json
   {
     "...": "...",
     "run_active": true,
     "active_alerts": ["CIRC_FAN_FAULT"],
     "fault_details": [
       {
         "code": "CIRC_FAN_FAULT",
         "source": "circulation",
         "tier": "fault",
         "message": "Current out of range after on() - possible fan fault"
       }
     ]
   }
   ```

   `GET /alerts` returns at least one row with
   `{"level": "ERROR", "tier": "fault", "source": "circulation",
   "code": "CIRC_FAN_FAULT", ...}`.

   The Kivy dashboard shows a red **FAULT** banner with the text
   `Circ fan fault` (or `FAULT: Circ fan fault`) within ~10 seconds of
   the run starting. Tapping the banner navigates to the Alerts tab
   where the same row is visible with both the **ERROR** log-level
   badge and the **FAULT** tier badge.

4. Disconnecting one of the SHT31 sensors causes
   `active_alerts` to contain the appropriate sensor code within 3 ticks.
5. Pulling the SD card mid-run causes `"SD_WRITE_FAIL"` to surface within
   3 ticks (does not require remount).
6. Forcing one of the unit tests to fail causes the equivalent runtime
   path to also fail and produce a fault. (Test the contract by patching
   the test to inject a known-bad reading.)
7. `test_modules.py` continues to pass for every module.
8. `main.py` integration test (run with no faults) shows
   `active_alerts == []` and `fault_details == []`.
9. With the firmware emitting `tier` on every alert, the Kivy app's
   `kilnapp/alerts.py` `FAULT_CODES` / `NOTICE_CODES` tables can be
   commented out and the dashboard / Alerts screen still classify
   correctly. (This validates that the firmware-side tagging is
   complete and the client fallback is genuinely a fallback.)

When all nine pass, the gap between "fault detected" and "operator sees
the fault" is closed.

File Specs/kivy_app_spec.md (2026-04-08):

# KIVY_APP_SPEC.md

Spec for the Kivy Android + desktop app for the kiln controller project.

---

## Overview

The app is the primary human interface for the kiln controller. It connects either
directly to the Pico 2W in AP mode (full control) or to the Pi4 daemon over cottage
WiFi (read-only monitoring). It is written in Python using the Kivy framework and
targets Android and desktop (Windows/macOS) for development.

---

## Connection Modes

### Auto-detect with manual override

On launch (and on manual refresh), the app attempts connections in order:

1. Try Pico AP IP (default `192.168.4.1`, port `80`) -- `GET /health`
2. If no response within 3 seconds, try Pi4 IP (user-configured), port `8080` --
   `GET /health`
3. If neither responds, try to connect to the pico in sta mode, at IP 10.0.0.24 (or other user configured IP)(port 80) -- `GET /health`
4. If none of the above respond, show "No connection" state

A connection mode indicator is always visible in the navigation bar:
- Green dot + "Direct" -- connected to Pico AP
- Blue dot + "Cottage" -- connected to Pi4 daemon
- Yellow dot + "Pico STA" -- connected to Pico in station mode (testing fallback)
- Red dot + "Offline" -- no connection

Manual override: a toggle in Settings forces a specific mode. When forced, the app
does not fall back to the other endpoint.

STA mode is primarily intended for development testing without needing to switch WiFi networks. In the document below 'AP' mode refers to both AP and STA modes, unless otherwise specified.

Auto-refresh retries connection every 30 seconds when offline.

### Mode-dependent UI

Screens and actions that are only available in AP/STA (Direct) mode are hidden or
shown as disabled with a "Direct connection required" tooltip in Cottage mode.
The app never silently attempts a control action when not in AP mode.

---

## Authentication

All requests to the Pico REST API include the header:

```
X-Kiln-Key: <api_key>
```

The API key is configured in Settings and stored in app local storage. On first
launch, the app prompts the user to enter the key. The key must match the value
in `config.py` on the Pico.

The Pi4 daemon REST API does not require authentication (LAN-only, read-only).

---

## Navigation

Bottom navigation bar with five tabs, always visible:

| Tab | Icon | Available in Cottage mode |
|-----|---|---|
| Dashboard | home | Yes |
| History | chart-line | Yes |
| Alerts | bell | Yes |
| Runs | list | Yes |
| Settings | gear | Ye |

AP-only screens (System Test, Schedules, Logs, Start Run, Moisture Calibration,
Module Upload) are accessed from the Dashboard or Settings, not from the bottom
nav. They are not reachable in Cottage mode.

---

## Screens

---

### Dashboard

The primary at-a-glance screen. Auto-refreshes every 10 seconds in AP mode,
every 35 seconds in Cottage mode.

**Status banner (top):**
- Current stage name and number (e.g. "Stage 3 of 9 -- Drying")
- Stage type badge: DRYING / EQUALIZING / CONDITIONING / IDLE / COOLDOWN
- Stage elapsed time (e.g. "14h 32m elapsed")
- Stage progress bar: elapsed vs. min_duration_h (fills to 100% at min duration,
  does not go beyond -- MC% and time both required to advance drying stages)

**Water pan banner (conditional):**
- Shown whenever current stage_type is "equalizing" or "conditioning"
- Persistent yellow banner: "Water pans may be needed -- check RH actual vs target"
- Dismissed only when stage changes

**Fault banner (conditional, highest priority):**
- Red banner for: heater_fault, sensor_failure, temp_out_of_range (sustained),
  rh_out_of_range (sustained)
- Shows alert code + message; tapping navigates to Alerts screen
- Overrides water pan banner in display priority

**Sensor readings (two columns):**

Left column -- Lumber zone (SHT31 at 0x44):
- Temperature: actual / target (colour: green within deadband, amber outside,
  red if fault)
- Relative humidity: actual / target (same colour scheme)

Right column -- Intake zone (SHT31 at 0x45):
- Temperature (actual only -- no target for intake)
- Relative humidity (actual only)

**Moisture content:**
- Channel 1: MC% (corrected) + raw resistance
- Channel 2: MC% (corrected) + raw resistance
- Target MC% for current stage (if drying stage)
- "Probe fault" if reading is None

**Equipment state row:**
- Heater: ON (red) / OFF (grey)
- Vents: OPEN / CLOSED
- Exhaust fan: ON + speed% / OFF
- Circulation fans: ON + speed% / OFF

**Rail currents (system health):**
- 12V rail: current in mA
- 5V rail: current in mA
- Shown as small indicators, not primary content

**LoRa link quality (Cottage mode only):**
- Signal strength bar (5 levels) derived from RSSI
- Raw RSSI dBm and SNR values
- Timestamp of last received packet (e.g. "Last update: 28s ago")

**Last update timestamp** (always visible, bottom of screen):
- In AP mode: "Updated Xs ago"
- In Cottage mode: "Last LoRa packet: Xs ago"

**AP mode action buttons (bottom, hidden in Cottage mode):**
- "Start Run" -- navigates to Start Run screen (disabled if run already active)
- "Stop Run" -- confirmation dialog, then POST /run/stop (shown only if run active)
- "Advance Stage" -- confirmation dialog, then POST /run/advance (shown only if
  run active and past min_duration_h)

---

### History Graphs

Time-series plots of logged data. Data source: Pi4 `/history` in Cottage mode,
Pico `/history` in AP mode.

**Time range selector (top):**
Predefined buttons: 1h | 6h | 24h | 72h | Full run
"Full run" loads data for the currently selected run (from Runs screen or current
active run).

**Run selector:**
Dropdown to choose which run's data to display. Defaults to current/most recent run.

**Plot tabs (five tabs):**

*Thermal*
- temp_lumber (solid line, primary colour)
- temp_intake (dashed line, secondary colour)
- target_temp stepped line (grey) -- derived from stage boundaries
- heater_on overlay (shaded band at bottom, red when on)
- Y axis: degrees C; X axis: elapsed time or wall clock time (toggle)

*Humidity*
- humidity_lumber (solid)
- humidity_intake (dashed)
- target_rh stepped line (grey)
- vent_open overlay (shaded band, blue when open)
- Y axis: % RH

*Moisture Content*
- channel_1 MC% (solid)
- channel_2 MC% (dashed)
- target_mc stepped line (grey, shown only during drying stages, null otherwise)
- Y axis: MC%

*Stage Timeline*
- Stage index as a step chart over time
- Stage name labels at each step boundary
- Run start/end markers

*Diagnostics*
- exhaust_fan_rpm (left Y axis)
- lora_rssi dBm (right Y axis, Cottage mode only)
- lora_snr (right Y axis, secondary, Cottage mode only)
- 12V rail current mA
- 5V rail current mA

**Implementation notes:**
- Use Kivy Garden graph widget or matplotlib embedded via FigureCanvasKivyAgg
- Columnar response from `/history` is unpacked client-side into per-field arrays
  before plotting -- do not iterate row-by-row for plot data
- Downsample server-side for ranges > 24h by passing `resolution` param to
  `/history` (see Pico REST API spec); Pi4 daemon handles decimation
- Empty state: "No data for this time range" placeholder

---

### Alerts

Scrollable chronological list of warnings and errors.

**Each alert row:**
- Timestamp (wall clock)
- Alert code (bold, e.g. HEATER_FAULT)
- Message text
- Value + limit if present (e.g. "temp=72.3 limit=65.0")
- Severity badge: WARNING (amber) / ERROR (red)

**Filter bar (top):**
- All | Errors only | Warnings only
- Run selector dropdown (filter by run)

**Empty state:** "No alerts recorded"

---

### Runs

List of all drying runs from the database.

**Each run row:**
- Run start date/time
- Schedule name
- Duration (if completed: total; if active: elapsed)
- Status badge: ACTIVE (green) / COMPLETED / INCOMPLETE

**Tap a run:**
- Opens a run detail view showing:
  - Schedule name and species/thickness label
  - Start/end timestamps and total duration
  - Stages completed
  - Final MC% readings at run end
  - "View history" button -- navigates to History Graphs with that run pre-selected

---

### System Test (AP mode only)

Runs all hardware unit tests on the Pico and streams results to the app.

**Launch:**
- "Run System Test" button
- Estimated duration shown (e.g. "~3-5 minutes including heater confirmation")
- Warning: "Ensure kiln is safe to operate during test -- heater and fans will
  activate briefly"
- Confirmation dialog before starting

**Results view (live-updating):**
- Each test is a row: test name | status | detail
- Status: PENDING (grey) | RUNNING (spinner) | PASS (green check) | FAIL (red X) |
  SKIP (grey dash)
- Tests grouped into sections:
  - Unit Tests (per module)
  - Integration Tests (cross-module, hardware in loop)
  - Commissioning Checks (heater temp rise, LoRa TX, RTC set)
- Progress bar: N of M tests complete
- Elapsed time

**Result summary (on completion):**
- Overall PASS / FAIL badge
- Count: X passed, Y failed, Z skipped
- "Save results" button -- downloads test report as timestamped text file
- "Copy to clipboard" button

**Polling model:**
- App POSTs to `/test/run` to start
- Polls `GET /test/status` every 1 second
- Pico streams results as tests complete; each poll returns full result array
  (idempotent, app diffs to detect new results)
- Final poll returns `"complete": true`

---

### Schedules (AP mode only)

List of schedule JSON files on the SD card.

**Each schedule row:**
- Schedule name (from JSON `name` field)
- Species + thickness label
- Number of stages
- Built-in badge (for the four factory schedules: maple_05in, maple_1in,
  beech_05in, beech_1in)
- Last modified date

**Actions per schedule:**
- View -- read-only table view of all stages
- Duplicate -- creates a copy with "_copy" suffix; opens editor
- Edit -- opens Schedule Editor (disabled for built-in schedules with a tooltip:
  "Duplicate to edit")
- Delete -- confirmation dialog; disabled for built-in schedules

**"New schedule" button:**
- Opens Schedule Editor with a blank template (single drying stage pre-populated)

---

### Schedule Editor (AP mode only)

Structured per-stage table editor.

**Header fields:**
- Schedule name (text field)
- Species (dropdown: maple / beech / oak / pine / other)
- Thickness (dropdown: 0.5 in / 1 in / custom)

**Stage table:**
Each row represents one stage with editable fields:
- Stage name (text, e.g. "Stage 1 - Initial warm-up")
- Stage type (dropdown: drying / equalizing / conditioning)
- Target temp C (numeric, 30-80)
- Target RH % (numeric, 20-95)
- Target MC % (numeric, required for drying; greyed out and set to null for
  equalizing/conditioning)
- Min duration h (numeric)
- Max duration h (numeric or blank for no limit)

**Stage controls:**
- Add stage (appends a row)
- Delete stage (remove row, with confirmation if not the last)
- Reorder (drag handle on each row)

**Validation on save:**
- All required fields present
- Stage types consistent with target_mc_pct rules (drying requires numeric MC%;
  equalizing/conditioning require null)
- Temperatures in valid range
- Min duration > 0
- At least one stage

**Save:**
- Validates, then PUTs JSON to Pico `/schedules/{filename}`
- Filename derived from schedule name (lowercase, underscores, .json suffix)
- Success: navigates back to Schedules list
- Error: shows inline validation messages or server error

---

### Logs (AP mode only)

List of log file sets on the SD card, one set per run.

**Each log set row:**
- Run date/time (from filename timestamp)
- Two file badges: EVENT LOG | DATA CSV
- File sizes

**Actions per log set:**
- View event log -- opens scrollable in-app text viewer (event_YYYYMMDD_HHMM.txt)
- Download event log -- saves to device Downloads folder
- Download data CSV -- saves to device Downloads folder
- Delete log set -- confirmation dialog; deletes both files for that run

**Storage indicator (top):**
- SD card used / total (from GET /sdcard/info)
- Warning if > 80% full

**In-app event log viewer:**
- Scrollable monospace text
- Filter by level: ALL | INFO | WARN | ERROR
- Search bar (substring match)

---

### Start Run (AP mode only)

Pre-run setup flow before starting a drying run.

**Step 1 -- Select schedule:**
- Species buttons: Maple | Beech | Other
- Thickness buttons: 0.5 inch | 1 inch | Custom
- Selecting species + thickness auto-selects the matching built-in schedule
  (maple_05in, maple_1in, beech_05in, beech_1in)
- "Or choose manually" -- opens schedule picker from full list
- Selected schedule name shown with stage count and estimated duration range

**Step 2 -- Run label (optional):**
- Free text label stored with the run record (e.g. "Workshop maple boards batch 1")

**Step 3 -- Pre-run checklist:**
Each item is a checkbox the user must tick before Start is enabled:
- [ ] Lumber loaded and stacked with spacers
- [ ] Moisture probes inserted into representative boards
- [ ] Water pans removed from kiln (initial drying stages)
- [ ] Kiln door sealed
- [ ] Extension cord connected and heater plugged in
- [ ] Adequate ventilation around kiln

**Start button:**
- Enabled only when all checklist items ticked
- Confirmation dialog: "Start [schedule name]? This will activate the heater and fans."
- POSTs to `/run/start` with schedule filename and label
- On success: navigates to Dashboard

---

### Moisture Calibration (AP mode only)

Calibrate per-channel MC% correction offsets against a handheld reference meter.

**Live readings panel:**
For each channel (channel_1, channel_2):
- Raw resistance (ohms)
- Corrected MC% (using current calibration offset)
- Current calibration offset (delta MC%)
- "Take reading" button -- triggers a fresh probe read

**Calibration entry:**
For each channel:
- Reference MC% field: user enters reading from handheld meter
- "Apply" button: computes offset = reference - corrected_before_offset; previews
  new corrected MC% with proposed offset applied
- "Save" button: POSTs updated calibration to `/calibration`; Pico writes
  calibration.json to SD card

**Reset:**
- "Reset to defaults" button: sets both offsets to 0.0; confirms before applying

**Notes panel:**
- "Calibrate with probes inserted in boards at operating temperature for best
  accuracy. Temperature correction is applied automatically during kiln runs."
- "Channel 1 and Channel 2 are positional (stack location), not species-specific.
  Species correction is set in the drying schedule."

**Current calibration display:**
- Shows channel_1 offset, channel_2 offset, last calibrated timestamp
- If calibration.json not found on SD: "No calibration file -- factory defaults
  in use (0.0 offset)"

---

### Module Upload (AP mode only)

Upload updated Python module files or schedule JSON files to the Pico over WiFi.

**Warning banner (persistent, always shown):**
"Uploading a broken module may render the kiln inoperable and require USB
recovery via mpremote. Keep a USB cable accessible. The Pico will reboot after
upload."

**File picker:**
- Accepts .py files and .json files only
- Shows selected filename and file size
- Rejects other file types with an error message

**Target path:**
- Pre-filled based on filename:
  - .py files: `lib/<filename>` (e.g. `lib/exhaust.py`)
  - .json files: `schedules/<filename>` (e.g. `schedules/maple_05in.json`)
  - `main.py` detected by name: target path set to `/main.py` with an additional
    warning: "Uploading main.py replaces the entry point. A syntax error will
    prevent the kiln from booting."
- Target path is editable

**Upload:**
- "Upload" button
- Progress bar (bytes sent / total)
- Success: "Upload complete. Pico rebooting..." then reconnection attempt after 5s
- Error: server error message displayed

**Installed modules list:**
- GET /modules returns list of installed .py files with sizes and last-modified
  timestamps
- Shown below the upload form for reference

---

### Settings

**Connection section:**
- Pico AP IP address (default: 192.168.4.1)
- Pico AP port (default: 80)
- Pi4 IP address
- Pi4 port (default: 8080)
- Connection mode override: Auto-detect | Force Direct | Force Cottage
- "Test connection" button for each endpoint

**Authentication section:**
- API key field (masked, show/hide toggle)
- "Save key" button

**RTC sync section:**
- "Sync Pico clock now" button -- POSTs current Unix timestamp to `/time`
- Last synced timestamp (from app local storage)
- "Auto-sync on connect" toggle (default: on)

**Daemon info section (populated from Pi4 /health):**
- Daemon environment: bench / cottage
- Daemon uptime
- Total packets received
- Last packet timestamp
- ntfy.sh topic name (display only)

**About section:**
- App version
- Pico firmware version (from GET /version)
- Connected Pico uptime (from GET /health)

---

## Data Flow Summary

### AP mode (Pico direct)

```
App --> HTTP GET/POST (port 80, X-Kiln-Key header) --> Pico REST API
     <-- JSON response
```

Refresh intervals:
- Dashboard: 10s auto-refresh
- History: on demand (time range change or manual refresh)
- Alerts: on demand
- System test: 1s polling during active test

### Cottage WiFi mode (Pi4 daemon)

```
App --> HTTP GET (port 8080, no auth) --> Pi4 REST API --> SQLite
     <-- JSON response
```

Refresh intervals:
- Dashboard: 35s auto-refresh
- History: on demand
- Alerts: on demand

---

## Error Handling

- HTTP timeout (>5s): show "Connection timeout" toast; mark connection as lost
- HTTP 401 (wrong API key): show "Authentication failed -- check API key in Settings"
- HTTP 500: show server error message from response body if present
- JSON parse error: show "Unexpected response from device"
- All errors logged to app local log (accessible via Settings > App Log)
- Connection lost during active test: show "Connection lost -- test may still be
  running on device"; offer "Reconnect and resume polling" button

---

## Local Storage (app-side)

Stored in app data directory (Android: internal storage; desktop: user config dir):

| Key | Content |
|-----|---|
| `pico_ip` | Pico AP IP address |
| `pi4_ip` | Pi4 IP address |
| `pi4_port` | Pi4 port |
| `api_key` | Pico API key (store obfuscated, not plaintext) |
| `connection_override` | auto / direct / cottage |
| `last_rtc_sync` | Unix timestamp of last successful RTC sync |
| `app_log` | Rolling last-100-lines app event log |

---

## Implementation Notes

- Target Kivy version: 2.3.x (current stable at time of writing)
- Use `kivymd` for Material Design widgets (cards, buttons, badges, bottom nav)
- History plots: use `kivy_garden.matplotlib` or embed `matplotlib` figures directly
- Android build: use `buildozer`; target Android API 31+
- Desktop: standard `python -m kivy` invocation; test on macOS and Windows
- All network calls are async (use `asyncio` or `threading` -- do not block the
  Kivy main thread)
- Schedule JSON editor: use a `RecycleView` for the stage table to handle
  schedules with many stages without performance issues
- Columnar history data from `/history`: unpack fields array + rows array into
  per-field lists before passing to matplotlib -- do not build dicts per row

---

## Open Items for Implementation

- Chart library final selection (kivy_garden.matplotlib vs. plotly in a WebView)
- Buildozer spec for Android packaging (permissions: INTERNET, WRITE_EXTERNAL_STORAGE)
- App icon and splash screen
- ntfy.sh topic configuration UI (if operator wants to change topic without SSH
  into Pi4)

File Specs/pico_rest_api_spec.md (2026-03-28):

# PICO_REST_API_SPEC.md

Spec for the HTTP REST API served by the Pico 2W in AP (Access Point) mode.
This API is consumed exclusively by the Kivy app when connected directly to the
Pico's WiFi AP.

---

## Overview

The Pico runs a lightweight HTTP server (MicroPython `asyncio`-based) alongside
the `schedule.tick()` control loop. The server listens on port 80. All endpoints
return JSON. The API is the full control interface for the kiln when the app is
on-site.

---

## Authentication

All requests must include the header:

```
X-Kiln-Key: <api_key>
```

The API key is a string configured in `config.py` on the Pico. If the header is
missing or the key does not match, the server returns:

```
HTTP 401
{"error": "unauthorized"}
```

The key is compared as a plain string. No hashing required -- this is a LAN-only
interface on a private AP network.

---

## General Conventions

- All responses are `Content-Type: application/json`
- All timestamps are Unix timestamps (integer seconds) unless noted
- All temperatures are degrees C (float)
- All humidity values are percent RH (float)
- All moisture content values are percent MC (float)
- Boolean fields use JSON `true`/`false`
- `null` is used for unavailable sensor readings (sensor failed, not yet read)
- HTTP 200 for success; HTTP 4xx for client errors; HTTP 500 for server errors
- Error responses always include `{"error": "<message>"}`

---

## Endpoints

---

### GET /health

Pico system health check. Used by app for connection detection and Settings display.

**Response:**

```json
{
  "status": "ok",
  "uptime_s": 3612,
  "free_mem_bytes": 142336,
  "sdcard_mounted": true,
  "rtc_set": true,
  "run_active": true,
  "firmware_version": "1.0.0"
}
```

| Field | Type | Notes |
|---|---|---|
| `status` | string | Always "ok" if server is responding |
| `uptime_s` | int | Seconds since Pico boot |
| `free_mem_bytes` | int | MicroPython `gc.mem_free()` |
| `sdcard_mounted` | bool | SD card currently mounted |
| `rtc_set` | bool | True if RTC year >= 2024 |
| `run_active` | bool | True if a drying run is in progress |
| `firmware_version` | string | From `config.py` VERSION constant |

---

### POST /time

Set the Pico RTC clock. Called automatically by the app on connect when
`rtc_set` is false or auto-sync is enabled.

**Request body:**

```json
{"ts": 1711900000}
```

`ts` is a Unix timestamp (integer). The server sets the RTC and responds:

```json
{"ok": true, "ts": 1711900000}
```

---

### GET /status

Current kiln state. Primary data source for the Dashboard. Returns the latest
values read by the control loop.

**Response:**

```json
{
  "ts": 1711900000,
  "run_active": true,
  "cooldown": false,
  "schedule_name": "Hard Maple 1 inch",
  "stage_index": 2,
  "stage_name": "Stage 3 - Drying",
  "stage_type": "drying",
  "stage_elapsed_h": 14.5,
  "stage_min_h": 24,
  "total_elapsed_h": 38.2,
  "target_temp_c": 49.0,
  "target_rh_pct": 70.0,
  "target_mc_pct": 25.0,
  "temp_lumber": 48.7,
  "rh_lumber": 71.2,
  "temp_intake": 22.4,
  "rh_intake": 55.1,
  "mc_channel_1": 27.3,
  "mc_channel_2": 26.8,
  "mc_resistance_1": 125400,
  "mc_resistance_2": 131200,
  "heater_on": false,
  "vent_open": false,
  "vent_reason": null,
  "exhaust_fan_pct": 0,
  "exhaust_fan_rpm": 0,
  "circ_fan_on": true,
  "circ_fan_pct": 75,
  "current_12v_ma": 412,
  "current_5v_ma": 89,
  "active_alerts": ["rh_out_of_range"]
}
```

| Field | Type | Notes |
|---|---|---|
| `ts` | int | Unix timestamp of this reading |
| `run_active` | bool | |
| `cooldown` | bool | True if in post-run cooldown |
| `schedule_name` | string or null | null if no schedule loaded |
| `stage_index` | int or null | 0-based |
| `stage_name` | string or null | |
| `stage_type` | string or null | "drying" / "equalizing" / "conditioning" |
| `stage_elapsed_h` | float or null | |
| `stage_min_h` | float or null | Minimum hours before advance |
| `total_elapsed_h` | float or null | |
| `target_temp_c` | float or null | |
| `target_rh_pct` | float or null | |
| `target_mc_pct` | float or null | null for equalizing/conditioning |
| `temp_lumber` | float or null | |
| `rh_lumber` | float or null | |
| `temp_intake` | float or null | |
| `rh_intake` | float or null | |
| `mc_channel_1` | float or null | Temperature-corrected MC% |
| `mc_channel_2` | float or null | Temperature-corrected MC% |
| `mc_resistance_1` | int or null | Raw ohms |
| `mc_resistance_2` | int or null | Raw ohms |
| `heater_on` | bool | |
| `vent_open` | bool | |
| `vent_reason` | string or null | "rh_high" / "temp_high" / null |
| `exhaust_fan_pct` | int | 0-100 |
| `exhaust_fan_rpm` | int or null | null if not available |
| `circ_fan_on` | bool | |
| `circ_fan_pct` | int | 0-100 |
| `current_12v_ma` | float or null | INA219 at 0x40 |
| `current_5v_ma` | float or null | INA219 at 0x41 |
| `active_alerts` | array of string | Alert codes currently in suppression window |

---

### GET /history

Time-series data for graphing. Returns data from the SD card CSV log for the
current or specified run.

**Query parameters:**

| Parameter | Type | Default | Notes |
|---|---|---|---|
| `start` | int | run start | Unix timestamp |
| `end` | int | now | Unix timestamp |
| `fields` | string | all fields | Comma-separated field names |
| `resolution` | int | 1 | Return every Nth row (decimation) |
| `run` | string | current | Run filename prefix (e.g. "20260328_1430") |

**Response (columnar format):**

```json
{
  "fields": ["ts", "temp_lumber", "rh_lumber", "mc_channel_1", "mc_channel_2"],
  "rows": [
    [1711900000, 48.7, 71.2, 27.3, 26.8],
    [1711900120, 48.9, 70.8, 27.1, 26.5]
  ],
  "run": "20260328_1430",
  "row_count": 2
}
```

Available fields (subset of logger.data() record keys):

```
ts, stage, stage_type, temp_lumber, rh_lumber, temp_intake, rh_intake,
mc_channel_1, mc_channel_2, heater, vents, vent_reason, exhaust_pct,
target_temp, target_rh, target_mc, stage_h, current_12v_ma, current_5v_ma
```

Note: The Pico reads CSV data from SD card. For long runs at 2-minute intervals,
a 7-day run produces ~5040 rows. Use `resolution=5` for 30-minute granularity.

**Error responses:**
- `404` if run not found or no log data for the specified time range
- `503` if SD card not mounted

---

### GET /alerts

Recent alert events from the SD event log.

**Query parameters:**

| Parameter | Type | Default | Notes |
|---|---|---|---|
| `limit` | int | 50 | Maximum rows to return |
| `level` | string | all | "WARNING" or "ERROR" to filter |
| `run` | string | current | Run filename prefix |

**Response:**

```json
{
  "alerts": [
    {
      "ts": 1711900000,
      "level": "WARNING",
      "source": "schedule",
      "message": "rh_out_of_range: actual=82.1 target=70.0 limit=78.0",
      "code": "rh_out_of_range"
    }
  ],
  "count": 1
}
```

The `code` field is extracted from the message if the message begins with a
known alert code (see schedule.py alert types). Falls back to null if not
parseable.

---
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

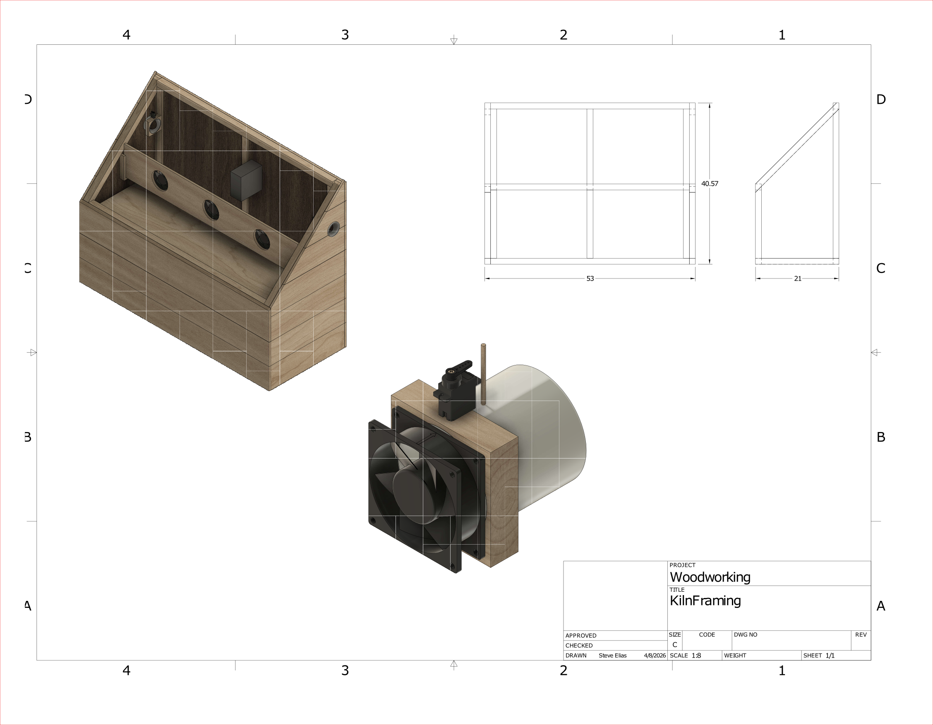
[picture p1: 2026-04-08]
KilnDrawing.png

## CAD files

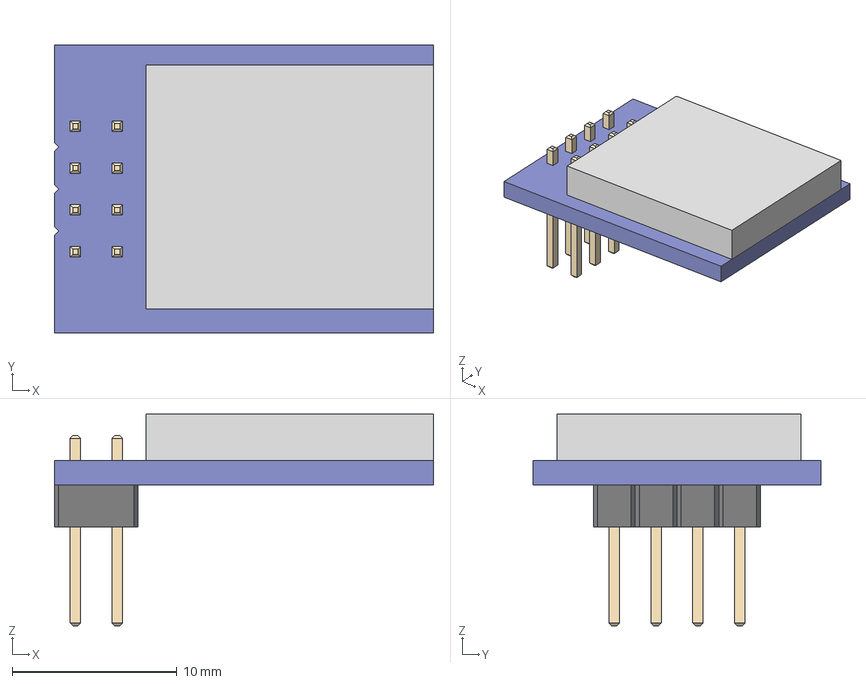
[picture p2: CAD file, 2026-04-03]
PCB/3d-models/LoRa Module.step
23.0 x 17.5 x 12.8 mm

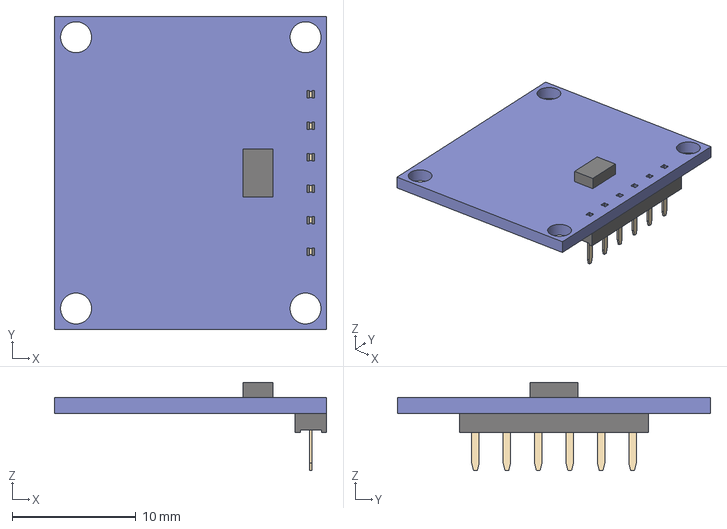
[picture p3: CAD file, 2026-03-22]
PCB/3d-models/INA219 Module.step
22.0 x 25.3 x 7.14 mm

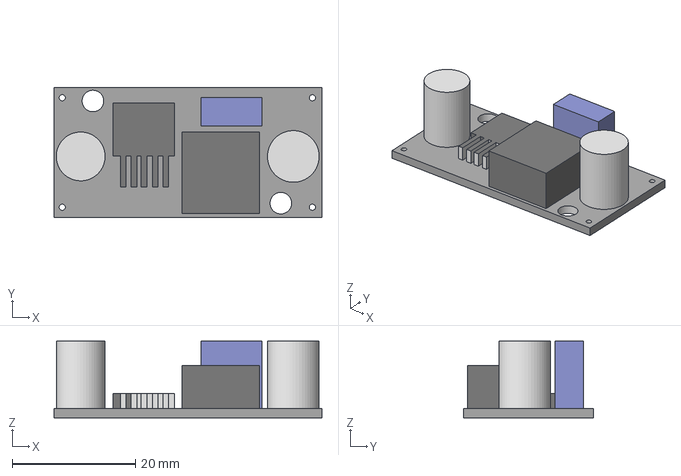
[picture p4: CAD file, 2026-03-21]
PCB/3d-models/LM2596.step
43.5 x 21.1 x 12.5 mm

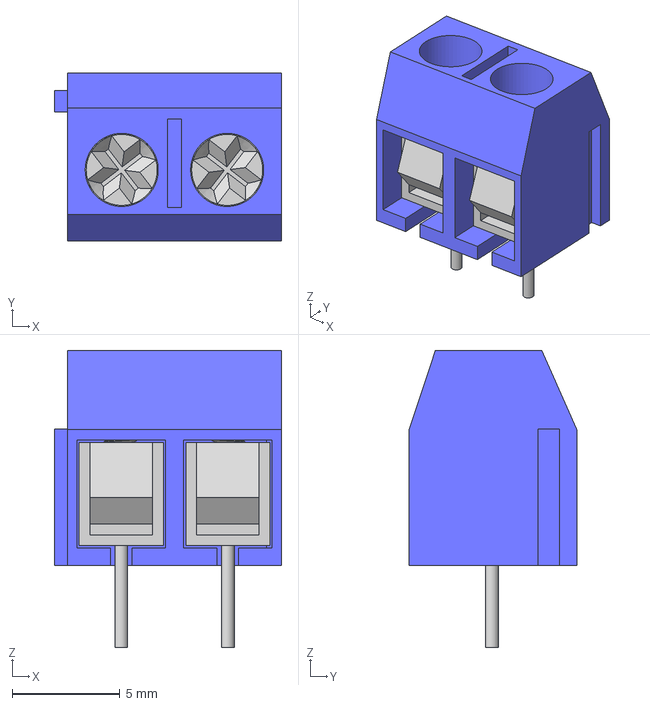
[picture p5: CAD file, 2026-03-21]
PCB/3d-models/2PinScrewTerminalBlockConnector.step
10.6 x 7.80 x 13.8 mm
Screw
Screw(Mirror) (3)

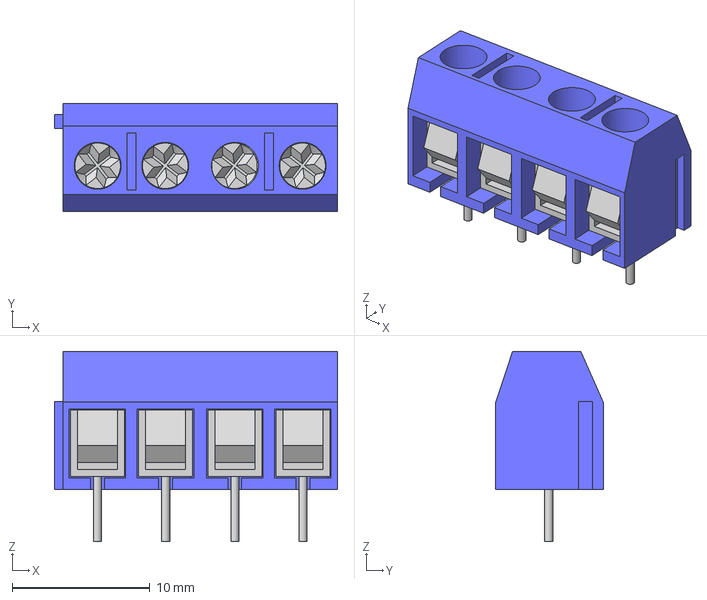
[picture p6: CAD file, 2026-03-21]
PCB/3d-models/4PinScrewTerminalBlockConnector.step
20.5 x 7.80 x 13.8 mm
Screw
Screw(Mirror) (3) x 3

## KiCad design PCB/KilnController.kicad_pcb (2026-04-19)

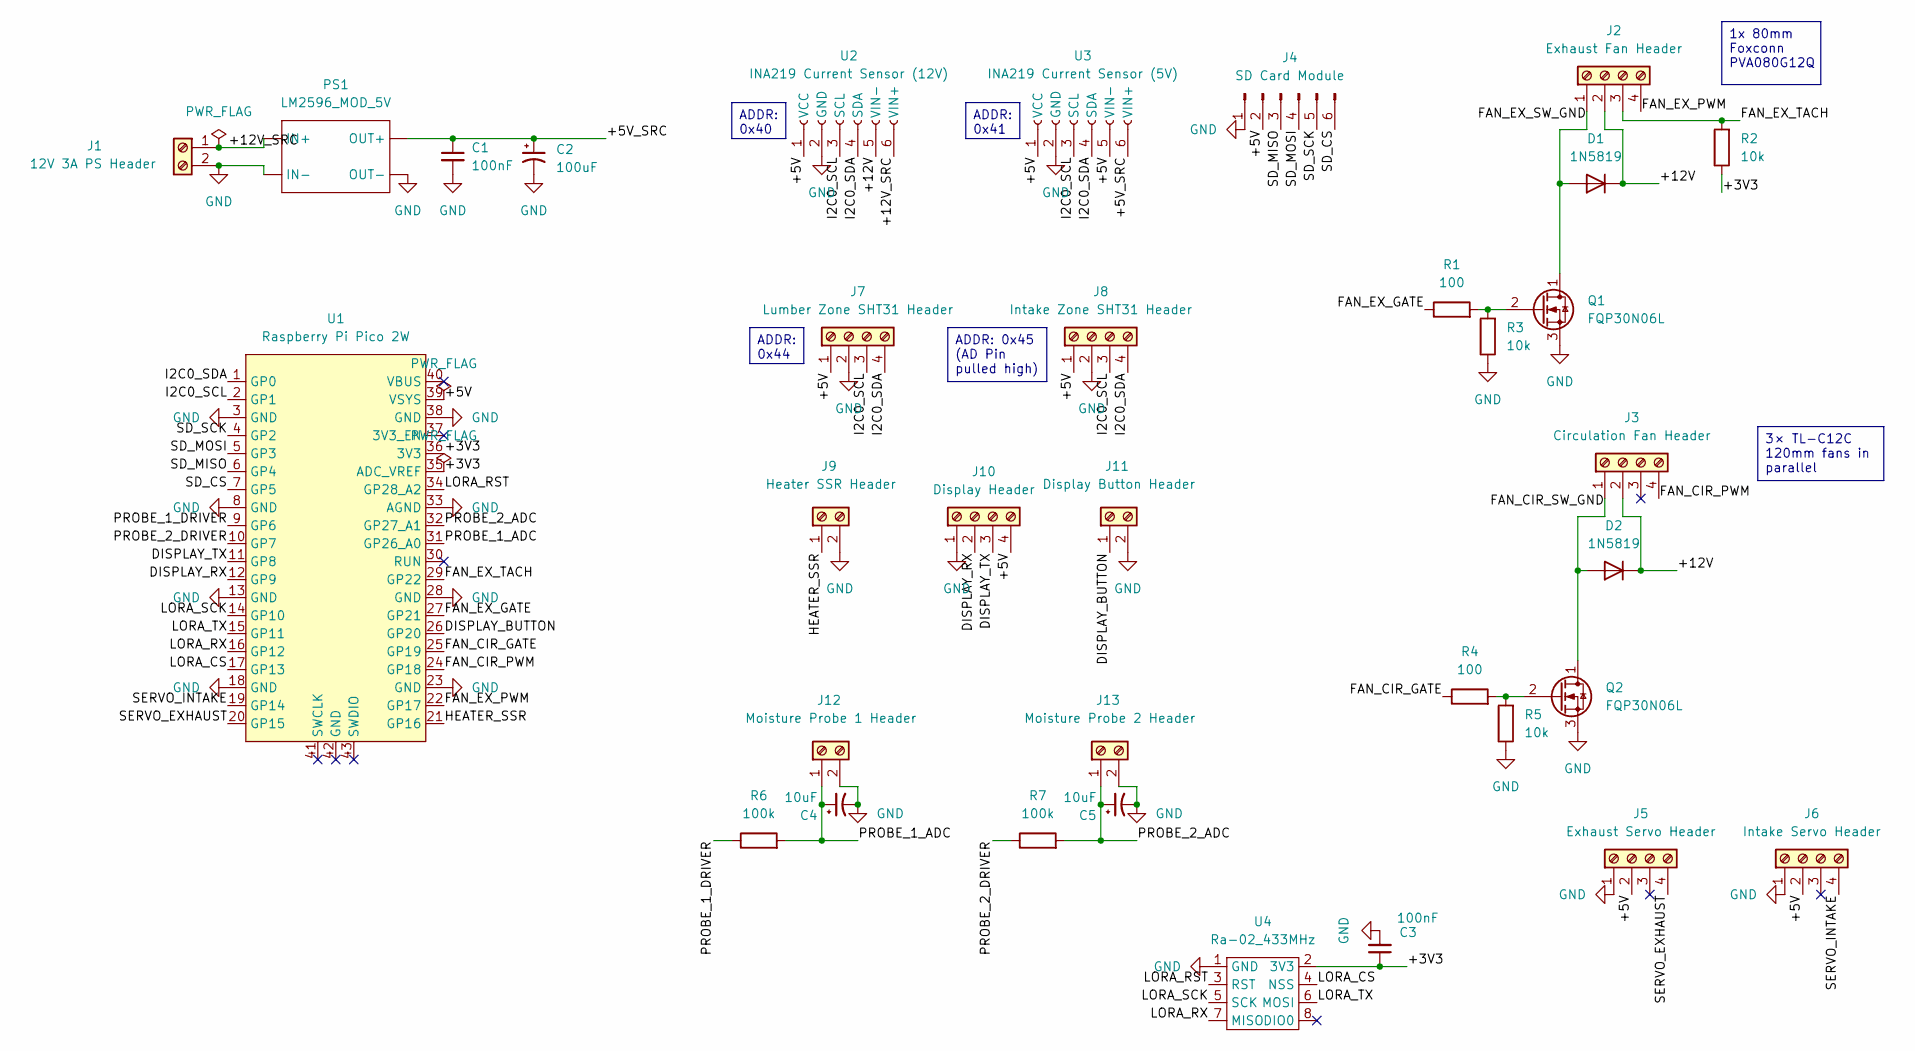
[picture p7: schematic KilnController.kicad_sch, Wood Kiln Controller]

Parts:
C1, C3: 100nF; C_Disc_D5.0mm_W2.5mm_P5.00mm
C2: 100uF; CP_Radial_D8.0mm_P3.50mm
C4, C5: 10uF; CP_Radial_D5.0mm_P2.00mm
D1, D2: 1N5819; D_DO-41_SOD81_P10.16mm_Horizontal
J1: 12V 3A PS Header; TerminalBlock_MetzConnect_Type101_RT01602HBWC_1x02_P5.08mm_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
J2: Exhaust Fan Header; TerminalBlock_MetzConnect_Type101_RT01604HBWC_1x04_P5.08mm_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
J3: Circulation Fan Header; TerminalBlock_MetzConnect_Type101_RT01604HBWC_1x04_P5.08mm_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
J4: SD Card Module; PinSocket_1x06_P2.54mm_Vertical
J5: Exhaust Servo Header; TerminalBlock_MetzConnect_Type101_RT01604HBWC_1x04_P5.08mm_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
J6: Intake Servo Header; TerminalBlock_MetzConnect_Type101_RT01604HBWC_1x04_P5.08mm_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
J7: Lumber Zone SHT31 Header; TerminalBlock_MetzConnect_Type101_RT01604HBWC_1x04_P5.08mm_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
J8: Intake Zone SHT31 Header; TerminalBlock_MetzConnect_Type101_RT01604HBWC_1x04_P5.08mm_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
J9: Heater SSR Header; TerminalBlock_MetzConnect_Type101_RT01602HBWC_1x02_P5.08mm_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
J10: Display Header; TerminalBlock_MetzConnect_Type101_RT01604HBWC_1x04_P5.08mm_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
J11: Display Button Header; TerminalBlock_MetzConnect_Type101_RT01602HBWC_1x02_P5.08mm_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
J12: Moisture Probe 1 Header; TerminalBlock_MetzConnect_Type101_RT01602HBWC_1x02_P5.08mm_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
J13: Moisture Probe 2 Header; TerminalBlock_MetzConnect_Type101_RT01602HBWC_1x02_P5.08mm_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
PS1: LM2596_MOD_5V; LM2596_Module_5V
Q1, Q2: FQP30N06L; TO-220-3_Vertical
R1, R4: 100; R_Axial_DIN0207_L6.3mm_D2.5mm_P10.16mm_Horizontal
R2, R3, R5: 10k; R_Axial_DIN0207_L6.3mm_D2.5mm_P10.16mm_Horizontal
R6, R7: 100k; R_Axial_DIN0207_L6.3mm_D2.5mm_P10.16mm_Horizontal
U1: Raspberry Pi Pico 2W; RaspberryPi_Pico_Common_THT
U2: INA219 Current Sensor (12V); INA219_Module
U3: INA219 Current Sensor (5V); INA219_Module
U4: Ra-02_433MHz; LoRa_Module

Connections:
/+3V3: C3.1, R2.1, U1.35 (ADC_VREF), U1.36 (3V3), U4.2 (3V3)
/+5V: J4.2, J5.2, J6.2, J7.1, J8.1, J10.4, U1.39 (VSYS), U2.1 (VCC), U3.1 (VCC), U3.5 (VIN-)
/+5V_SRC: C1.1, C2.1, PS1.3 (OUT+), U3.6 (VIN+)
/+12V: D1.1 (K), D2.1 (K), J2.2, J3.2, U2.5 (VIN-)
/+12V_SRC: J1.1, PS1.1 (IN+), U2.6 (VIN+)
/DISPLAY_BUTTON: J11.1, U1.26 (GP20)
/DISPLAY_RX: J10.2, U1.12 (GP9)
/DISPLAY_TX: J10.3, U1.11 (GP8)
/FAN_CIR_GATE: R4.1, U1.25 (GP19)
/FAN_CIR_PWM: J3.4, U1.24 (GP18)
/FAN_CIR_SW_GND: D2.2 (A), J3.1, Q2.1 (D)
/FAN_EX_GATE: R1.1, U1.27 (GP21)
/FAN_EX_PWM: J2.4, U1.22 (GP17)
/FAN_EX_SW_GND: D1.2 (A), J2.1, Q1.1 (D)
/FAN_EX_TACH: J2.3, R2.2, U1.29 (GP22)
/HEATER_SSR: J9.1, U1.21 (GP16)
/I2C0_SCL: J7.3, J8.3, U1.2 (GP1), U2.3 (SCL), U3.3 (SCL)
/I2C0_SDA: J7.4, J8.4, U1.1 (GP0), U2.4 (SDA), U3.4 (SDA)
/LORA_CS: U1.17 (GP13), U4.4 (NSS)
/LORA_RST: U1.34 (GP28_A2), U4.3 (RST)
/LORA_RX: U1.16 (GP12), U4.7 (MISO)
/LORA_SCK: U1.14 (GP10), U4.5 (SCK)
/LORA_TX: U1.15 (GP11), U4.6 (MOSI)
/PROBE_1_ADC: C4.1, J12.1, R6.2, U1.31 (GP26_A0)
/PROBE_1_DRIVER: R6.1, U1.9 (GP6)
/PROBE_2_ADC: C5.1, J13.1, R7.2, U1.32 (GP27_A1)
/PROBE_2_DRIVER: R7.1, U1.10 (GP7)
/SD_CS: J4.6, U1.7 (GP5)
/SD_MISO: J4.3, U1.6 (GP4)
/SD_MOSI: J4.4, U1.5 (GP3)
/SD_SCK: J4.5, U1.4 (GP2)
/SERVO_EXHAUST: J5.4, U1.20 (GP15)
/SERVO_INTAKE: J6.4, U1.19 (GP14)
GND: C1.2, C2.2, C3.2, C4.2, C5.2, J1.2, J4.1, J5.1, J6.1, J7.2, J8.2, J9.2, J10.1, J11.2, J12.2, J13.2, PS1.2 (IN-), PS1.4 (OUT-), Q1.3 (S), Q2.3 (S), R3.1, R5.1, U1.3 (GND), U1.8 (GND), U1.13 (GND), U1.18 (GND), U1.23 (GND), U1.28 (GND), U1.33 (AGND), U1.38 (GND), U2.2 (GND), U3.2 (GND), U4.1 (GND)
unnamed: Q1.2 (G), R1.2, R3.2
unnamed: Q2.2 (G), R4.2, R5.2

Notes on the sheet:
1x 80mm Foxconn PVA080G12Q
ADDR: 0x45 (AD Pin pulled high)
ADDR: 0x40
3× TL-C12C 120mm fans in parallel
ADDR: 0x41
ADDR: 0x44

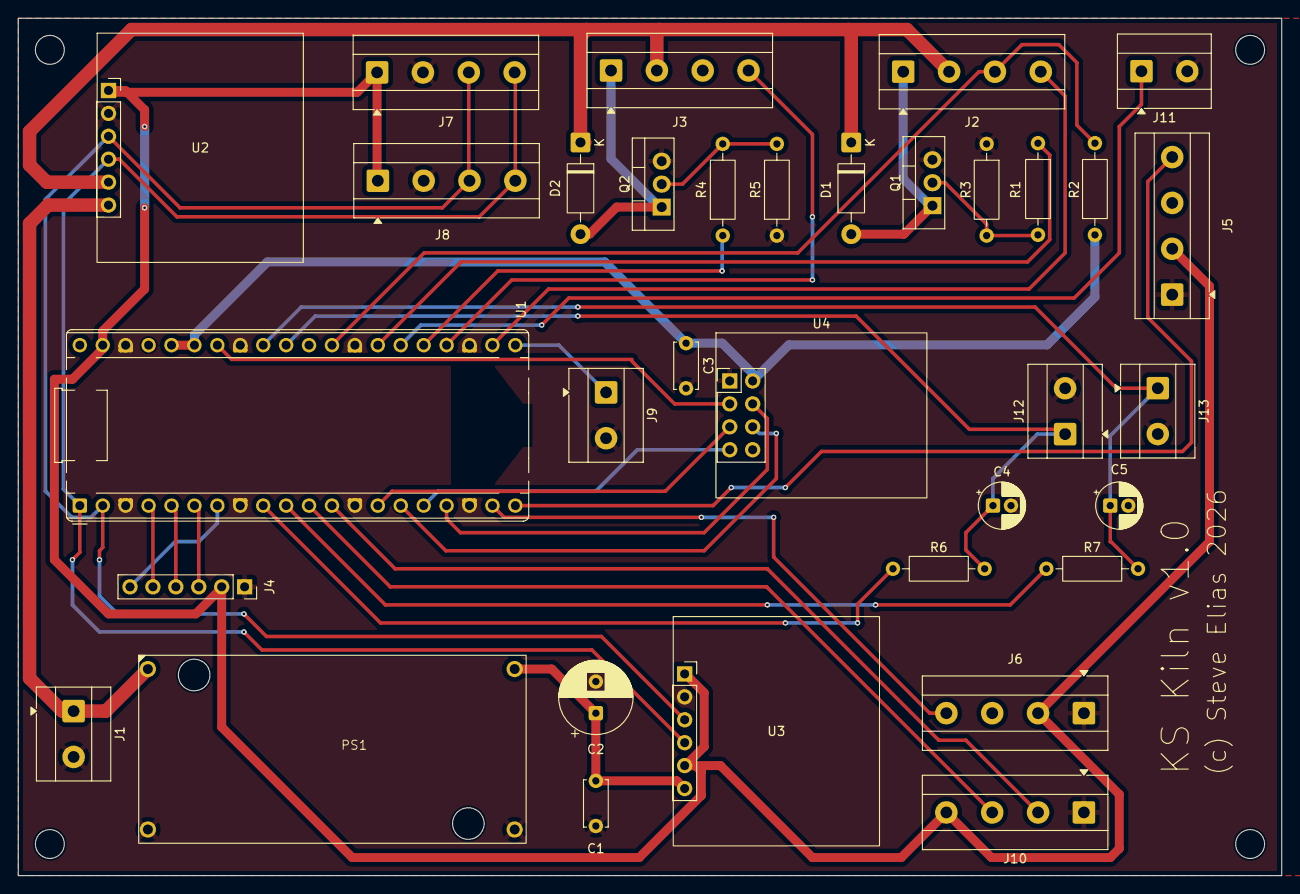
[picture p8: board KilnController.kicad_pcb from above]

Board: 2 copper layers, 140.0 x 95.0 mm, 34 parts (0 on the bottom side), 36 nets.

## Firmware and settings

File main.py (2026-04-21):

# main.py -- Kiln controller entry point
#
# Initialises all hardware modules, starts the WiFi AP, runs the
# asyncio HTTP REST API server, and executes the drying control loop.
# Runs at boot on the Raspberry Pi Pico 2 W.

# --- Kill switch check (set by boot.py) ---
# If boot.py was interrupted with Ctrl-C, or /no_main exists, bail out
# immediately and drop to the REPL without touching any hardware.
import builtins

if getattr(builtins, "_kiln_skip_main", False):
    print("main.py: skip flag set by boot.py -- not starting controller.")
    import sys

    sys.exit(0)

import machine
import network
import time
import gc
import uos
import asyncio

try:
    import ujson as json
except ImportError:
    import json

import config
from lib.sdcard import SDCard
from lib.logger import Logger
from lib.SHT31sensors import SHT31Sensors
from lib.current import CurrentMonitor
from lib.circulation import CirculationFans
from lib.exhaust import ExhaustFan
from lib.vents import Vents
from lib.heater import Heater
from lib.moisture import MoistureProbe
from lib.display import Display, Color
from lib.lora import LoRa
from lib.schedule import KilnSchedule

# -----------------------------------------------------------------------
# Module-level state
# -----------------------------------------------------------------------

_boot_ticks = time.ticks_ms()
_status_cache = {}
_test_results = []
_test_running = False
_cached_rpm = None

# Module instances (populated by init_hardware)
sdcard = None
logger = None
i2c0 = None
sensors = None
monitor_12v = None
monitor_5v = None
circulation = None
exhaust = None
vents = None
heater = None
moisture = None
display = None
lora = None
schedule = None

# -----------------------------------------------------------------------
# Alert tier table (authoritative source for severity classification)
# -----------------------------------------------------------------------
# Copied from KivyApp/kilnapp/alerts.py FAULT_CODES / NOTICE_CODES.
# Everything not listed defaults to "info".
ALERT_CODE_TIERS = {
    # Hardware / firmware faults (tier = "fault")
    "CIRC_FAN_FAULT": "fault",
    "EXHAUST_FAN_STALL": "fault",
    "VENT_STALL": "fault",
    "SENSOR_LUMBER_FAIL": "fault",
    "SENSOR_INTAKE_FAIL": "fault",
    "SENSOR_FAILURE": "fault",
    "MOISTURE_PROBE_FAIL": "fault",
    "HEATER_TIMEOUT": "fault",
    "HEATER_FAULT": "fault",
    "TEMP_OOR": "fault",
    "RH_OOR": "fault",
    "TEMP_OUT_OF_RANGE": "fault",
    "RH_OUT_OF_RANGE": "fault",
    "OVER_TEMP": "fault",
    "SD_FAIL": "fault",
    "SD_WRITE_FAIL": "fault",
    "LORA_FAIL": "fault",
    "LORA_TIMEOUT": "fault",
    "CURRENT_12V_FAIL": "fault",
    "CURRENT_5V_FAIL": "fault",
    "DISPLAY_FAIL": "fault",
    "MODULE_CHECK_FAILED": "fault",
    # Procedural / batch notices (tier = "notice")
    "STAGE_GOAL_NOT_MET": "notice",
    "STAGE_GOAL_NOT_REACHED": "notice",
    "WATER_PAN_REMINDER": "notice",
}

# Built-in schedule filenames (read-only)
BUILTIN_SCHEDULES = (
    "maple_05in.json",
    "maple_1in.json",
    "beech_05in.json",
    "beech_1in.json",
)

# HTTP status text
HTTP_STATUS = {
    200: "OK",
    400: "Bad Request",
    401: "Unauthorized",
    403: "Forbidden",
    404: "Not Found",
    409: "Conflict",
    413: "Payload Too Large",
    500: "Internal Server Error",
    503: "Service Unavailable",
}

# -----------------------------------------------------------------------
# Hardware initialisation
# -----------------------------------------------------------------------


def _try_init(label, fn):
    """Run a hardware init step, logging any failure but not raising.

    Returns the result of fn() on success, or None on failure.
    Critical for boot resilience -- a single failed peripheral must not
    crash the whole controller into a boot loop.

    Prints a "starting" line before and a "done" / "FAILED" line after,
    so a hang can be diagnosed by reading the last printed line over USB.
    """
    print(f"[init] {label} ...", end="")
    # Force the print to flush immediately so it is visible even if the
    # next call hangs and never returns.
    try:
        import sys

        sys.stdout.flush()
    except Exception:
        pass
    t0 = time.ticks_ms()
    try:
        result = fn()
        elapsed = time.ticks_diff(time.ticks_ms(), t0)
        print(f" OK ({elapsed}ms)")
        return result
    except Exception as e:
        elapsed = time.ticks_diff(time.ticks_ms(), t0)
        print(f" FAILED after {elapsed}ms: {e}")
        if logger is not None:
            try:
                logger.event("main", f"{label} init failed: {e}", level="ERROR")
            except Exception:
                pass
        return None


def init_hardware():
    global sdcard, logger, i2c0, sensors, monitor_12v, monitor_5v
    global circulation, exhaust, vents, heater, moisture
    global display, lora, schedule

    # 1. SD card first -- logger depends on it
    sdcard = _try_init("SDCard", lambda: SDCard())

    # 2. Logger (must succeed -- needed by everything else for log events)
    if sdcard is not None:
        _logger = Logger(sdcard)
        logger = _logger
        # Open the persistent system log so boot events get persisted
        _try_init("system log", lambda: _logger.open_system_log())

    # 3. Shared I2C bus
    i2c0 = _try_init(
        "I2C0",
        lambda: machine.I2C(0, sda=machine.Pin(0), scl=machine.Pin(1), freq=100_000),
    )

    # 4. Sensors
    if i2c0 is not None:
        sensors = _try_init(
            "SHT31Sensors", lambda: SHT31Sensors(i2c=i2c0, logger=logger)
        )

    # 5. Current monitors
    if i2c0 is not None:
        monitor_12v = _try_init(
            "CurrentMonitor 12V",
            lambda: CurrentMonitor(i2c0, 0x40, "12V", logger=logger),
        )
        monitor_5v = _try_init(
            "CurrentMonitor 5V",
            lambda: CurrentMonitor(i2c0, 0x41, "5V", logger=logger),
        )

    # 6. Circulation fans
    circulation = _try_init(
        "CirculationFans",
        lambda: CirculationFans(current_monitor=monitor_12v, logger=logger),
    )

    # 7. Exhaust fan
    exhaust = _try_init("ExhaustFan", lambda: ExhaustFan(logger=logger))

    # 8. Vents
    vents = _try_init("Vents", lambda: Vents(current_monitor=monitor_5v, logger=logger))

    # 9. Heater
    heater = _try_init("Heater", lambda: Heater(logger=logger))

    # 10. Moisture probes + calibration
    moisture = _try_init("MoistureProbe", lambda: MoistureProbe(logger=logger))
    if moisture is not None and sdcard is not None:
        _load_calibration(moisture, sdcard)

    # 11. Display
    display = _try_init("Display", lambda: Display(timeout_s=config.DISPLAY_TIMEOUT_S))

    # 12. LoRa
    lora = _try_init("LoRa", lambda: LoRa(logger=logger))

    # 13. Schedule controller (requires all critical hardware -- skip if missing)
    required = (sdcard, sensors, moisture, heater, exhaust, circulation, vents, lora)
    if all(x is not None for x in required):
        schedule = _try_init(
            "KilnSchedule",
            lambda: KilnSchedule(
                sdcard=sdcard,
                sensors=sensors,
                moisture=moisture,
                heater=heater,
                exhaust=exhaust,
                circulation=circulation,
                vents=vents,
                lora=lora,
                logger=logger,
            ),
        )
    else:
        missing = [
            n
            for n, x in zip(
                (
                    "sdcard",
                    "sensors",
                    "moisture",
                    "heater",
                    "exhaust",
                    "circulation",
                    "vents",
                    "lora",
                ),
                required,
            )
            if x is None
        ]
        print(f"[init] KilnSchedule SKIPPED -- missing: {missing}")
        if logger is not None:
            logger.event(
                "main", f"KilnSchedule skipped, missing: {missing}", level="ERROR"
            )


# -----------------------------------------------------------------------
# Calibration loader
# -----------------------------------------------------------------------


def _load_calibration(moisture_probe, sd):
    text = sd.read_text("calibration.json")
    if text is None:
        return
    try:
        cal = json.loads(text)
        moisture_probe.set_calibration(
            channel_1_offset=cal.get("channel_1_offset", 0.0),
            channel_2_offset=cal.get("channel_2_offset", 0.0),
        )
    except Exception as e:
        print(f"[main] WARNING: Calibration load failed: {e}")


# -----------------------------------------------------------------------
# WiFi
# -----------------------------------------------------------------------


def start_wifi():
    """
    Bring up the WiFi interface based on config.WIFI_MODE.

    "ap"  -- Pico hosts its own access point (production)
    "sta" -- Pico joins an existing WiFi network (development)
    """
    mode = getattr(config, "WIFI_MODE", "ap").lower()
    if mode == "sta":
        return _start_wifi_sta()
    return _start_wifi_ap()


def _start_wifi_ap():
    # cyw43 driver on Pico W / Pico 2 W:
    #   - WPA2 password must be 8-63 ASCII characters
    #   - config must be set BEFORE active(True)
    #   - the AP can only be started/stopped once per reboot
    pw = config.AP_PASSWORD
    if pw and len(pw) < 8:
        print(
            f"[main] WARNING: AP_PASSWORD is {len(pw)} chars; "
            f"WPA2 requires 8-63. AP will fall back to open."
        )

    ap = network.WLAN(network.AP_IF)
    if pw and len(pw) >= 8:
        ap.config(essid=config.AP_SSID, password=pw)
        sec = "WPA2"
    else:
        ap.config(essid=config.AP_SSID)
        sec = "open"
    ap.active(True)

    for _ in range(50):
        if ap.active():
            break
        time.sleep_ms(100)

    ip = ap.ifconfig()[0]
    logger.event("main", f"WiFi AP active -- SSID={config.AP_SSID} IP={ip} ({sec})")
    return ap


def _start_wifi_sta():
    """
    Connect to an existing WiFi network as a station.
    Used in development so other machines on the LAN can hit the REST API.
    """
    ssid = config.STA_SSID
    pw = config.STA_PASSWORD

    sta = network.WLAN(network.STA_IF)
    sta.active(True)

    def _log(msg, level="INFO"):
        if logger is not None:
            logger.event("main", msg, level=level)
        else:
            print(f"[main] {msg}")

    if sta.isconnected():
        # Already connected from a previous boot? Reuse it.
        ip = sta.ifconfig()[0]
        _log(f"WiFi STA already connected -- SSID={ssid} IP={ip}")
        return sta

    print(f"[main] Connecting to WiFi SSID={ssid} ...")
    sta.connect(ssid, pw)

    # Wait up to 20 seconds for association + DHCP
    for _ in range(200):
        if sta.isconnected():
            break
        time.sleep_ms(100)

    if not sta.isconnected():
        status = sta.status()
        _log(f"WiFi STA failed to connect to {ssid} (status={status})", level="ERROR")
        return sta

    cfg = sta.ifconfig()
    ip = cfg[0]
    gateway = cfg[2]
    _log(f"WiFi STA connected -- SSID={ssid} IP={ip} GW={gateway}")
    return sta


# -----------------------------------------------------------------------
# RTC sync
# -----------------------------------------------------------------------


def set_rtc(unix_ts):
    t = time.localtime(unix_ts)
    machine.RTC().datetime((t[0], t[1], t[2], t[6], t[3], t[4], t[5], 0))


def _rtc_is_set():
    return time.localtime()[0] >= 2024


# -----------------------------------------------------------------------
# Uptime helper
# -----------------------------------------------------------------------


def _uptime_s():
    return time.ticks_diff(time.ticks_ms(), _boot_ticks) // 1000


# -----------------------------------------------------------------------
# Status cache
# -----------------------------------------------------------------------

# Fault -> ntfy bridge state. Module faults live inside the telemetry
# `faults` array; without an explicit ALERT;... packet the Pi4 daemon
# stores them but never pushes an ntfy notification. We diff the active
# fault set each tick and emit ALERT;... for any newly-active code,
# rate-limited per-code to mirror schedule._send_alert()'s suppression.
_last_fault_codes = set()
_fault_alert_sent_ms = {}
FAULT_ALERT_SUPPRESS_MS = 30 * 60 * 1000  # 30 min per code


def _collect_module_faults():
    """Poll all modules for fault state and return aggregated results.

    Returns (codes, details) where:
    - codes: list of fault code strings (deduped, faults first)
    - details: list of {code, source, message, tier} dicts
    """
    faults = []  # list of (code, source, message, tier)
    for source, mod in (
        ("circulation", circulation),
        ("exhaust", exhaust),
        ("vents", vents),
        ("heater", heater),
        ("sensors", sensors),
        ("moisture", moisture),
        ("current_12v", monitor_12v),
        ("current_5v", monitor_5v),
        ("lora", lora),
        ("sdcard", sdcard),
        ("logger", logger),
        ("display", display),
    ):
        if mod is None:
            continue
        try:
            if hasattr(mod, "check_health"):
                mod.check_health()
        except Exception as e:
            faults.append((
                "MODULE_CHECK_FAILED",
                source,
                str(e)[:80],
                "fault",
            ))
            continue
        if getattr(mod, "fault", False):
            code = getattr(mod, "fault_code", None) or "UNKNOWN_FAULT"
            msg = getattr(mod, "fault_message", None) or ""
            tier = getattr(mod, "fault_tier", "fault")
            faults.append((code, source, msg, tier))

    # Build deduped code list and detail list
    seen = set()
    codes = []
    details = []
    # Sort: faults first, then notices, then info
    tier_order = {"fault": 0, "notice": 1, "info": 2}
    faults.sort(key=lambda x: tier_order.get(x[3], 2))
    for code, src, msg, tier in faults:
        if code not in seen:
            seen.add(code)
            codes.append(code)
        details.append({
            "code": code,
            "source": src,
            "message": msg,
            "tier": tier,
        })
    return codes, details


def _update_status_cache():
    """Build the status cache, tolerating any missing modules."""
    global _status_cache

    # Schedule may be None if init failed -- use an empty dict so .get() works
    s = {}
    sensor_data = {}
    mc_data = {}
    total_h = None
    stage_min_h = None
    active_alerts = []
    if schedule is not None:
        try:
            s = schedule.status() or {}
        except Exception as e:
            print(f"[main] schedule.status() failed: {e}")
        try:
            sensor_data = schedule._last_sensor_read or {}
        except Exception:
            pass
        try:
            mc_data = schedule._last_mc_read or {}
        except Exception:
            pass
        try:
            if schedule.is_running and schedule._run_start_ms:
                elapsed = time.ticks_diff(time.ticks_ms(), schedule._run_start_ms)
                total_h = round(elapsed / 3_600_000, 2)
        except Exception:
            pass
        try:
            if schedule._schedule and schedule.is_running:
                stages = schedule._schedule.get("stages", [])
                idx = schedule._stage_index
                if 0 <= idx < len(stages):
                    stage_min_h = stages[idx].get("min_duration_h")
        except Exception:
            pass
        try:
            now = time.ticks_ms()
            for atype, ts in schedule._last_alert_ts.items():
                if time.ticks_diff(now, ts) < 30 * 60_000:
                    active_alerts.append(atype)
        except Exception:
            pass

    # Idle direct reads: when no run is active the schedule.tick() loop is
    # not refreshing the sensor / moisture caches, so /status would otherwise
    # return None for every temperature, humidity, and MC field. Read the
    # sensors directly here so the Kivy dashboard (and any other client) can
    # see live values at idle. This block is skipped while a run is active so
    # the schedule's cached reads remain authoritative during a drying run.
    run_active = bool(s.get("running", False))
    if not run_active:
        if sensors is not None:
            try:
                idle_sensor = sensors.read()
                if idle_sensor:
                    sensor_data = idle_sensor
                    # Lumber temp/RH are read from `s` further down via
                    # actual_temp_c / actual_rh_pct - inject them so the
                    # idle path uses the same field names.
                    s["actual_temp_c"] = idle_sensor.get("temp_lumber")
                    s["actual_rh_pct"] = idle_sensor.get("rh_lumber")
            except Exception as e:
                print(f"[main] idle sensors.read() failed: {e}")
        if moisture is not None:
            try:
                idle_mc = moisture.read()
                if idle_mc:
                    mc_data = idle_mc
                    s["actual_mc_maple"] = idle_mc.get("ch1_mc_pct")
                    s["actual_mc_beech"] = idle_mc.get("ch2_mc_pct")
            except Exception as e:
                print(f"[main] idle moisture.read() failed: {e}")

    cur_12v = None
    cur_5v = None
    if monitor_12v is not None:
        try:
            r12 = monitor_12v.read()
            if r12:
                cur_12v = r12.get("current_mA")
        except Exception:
            pass
    if monitor_5v is not None:
        try:
            r5 = monitor_5v.read()
            if r5:
                cur_5v = r5.get("current_mA")
        except Exception:
            pass

    # --- Fault aggregator ---
    # Poll all modules for fault state and merge with schedule alerts.
    # Runs in both idle and run-active paths (spec normative req #3).
    mod_codes, mod_details = _collect_module_faults()

    # Merge schedule-emitted alerts (from _last_alert_ts) into fault_details.
    # Schedule alerts carry their own codes; look up tier from the static table.
    for acode in active_alerts:
        code_upper = acode.upper()
        tier = ALERT_CODE_TIERS.get(code_upper, ALERT_CODE_TIERS.get(acode, "info"))
        if code_upper not in (d["code"] for d in mod_details):
            mod_details.append({
                "code": code_upper,
                "source": "schedule",
                "message": "",
                "tier": tier,
            })
        if code_upper not in mod_codes:
            mod_codes.append(code_upper)

    # Rebuild active_alerts: combine module faults + schedule alerts, deduped.
    all_alert_codes = mod_codes

    _status_cache = {
        "ts": time.time() if _rtc_is_set() else 0,
        "run_active": s.get("running", False),
        "active_run_id": logger.run_id if logger is not None else None,
        "cooldown": s.get("cooldown", False),
        "schedule_name": s.get("schedule_name"),
        "stage_index": s.get("stage_index"),
        "stage_name": s.get("stage_name"),
        "stage_type": s.get("stage_type"),
        "stage_elapsed_h": s.get("stage_elapsed_h"),
        "stage_min_h": stage_min_h,
        "total_elapsed_h": total_h,
        "target_temp_c": s.get("target_temp_c"),
        "target_rh_pct": s.get("target_rh_pct"),
        "target_mc_pct": s.get("target_mc_pct"),
        "temp_lumber": s.get("actual_temp_c"),
        "rh_lumber": s.get("actual_rh_pct"),
        "temp_intake": sensor_data.get("temp_intake"),
        "rh_intake": sensor_data.get("rh_intake"),
        "mc_channel_1": s.get("actual_mc_maple"),
        "mc_channel_2": s.get("actual_mc_beech"),
        "mc_resistance_1": _safe_int(mc_data.get("ch1_ohms")),
        "mc_resistance_2": _safe_int(mc_data.get("ch2_ohms")),
        "heater_on": s.get("heater_on", False),
        "vent_open": s.get("vents_open", False),
        "vent_reason": s.get("vent_reason"),
        "exhaust_fan_pct": exhaust.speed_pct if exhaust else 0,
        "exhaust_fan_rpm": _cached_rpm,
        "circ_fan_on": circulation.is_running if circulation else False,
        "circ_fan_pct": circulation.speed_pct if circulation else 0,
        "current_12v_ma": cur_12v,
        "current_5v_ma": cur_5v,
        "active_alerts": all_alert_codes,
        "fault_details": mod_details,
        "degraded_modules": _missing_modules(),
    }

    _emit_new_fault_alerts(mod_details)
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

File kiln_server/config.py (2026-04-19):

"""kiln_server configuration.

This is the only file that differs between bench and cottage deployments.
Edit the values below to match the target Pi4.
"""

# "bench" or "cottage" -- surfaced in /health so the Kivy app can show which
# Pi4 it is talking to.
ENVIRONMENT = "cottage"

# --- LoRa SPI wiring (BCM GPIO numbering) ------------------------------------
SPI_BUS = 0
SPI_CE = 0  # CE0 -> GPIO8
DIO0_PIN = 25  # RX-done interrupt
RST_PIN = 17  # Ra-02 reset (active low)

# --- LoRa RF parameters (must match Pico TX side) ----------------------------
LORA_FREQ_MHZ = 433.0
LORA_SF = 9
LORA_BW_HZ = 125_000
LORA_CR = 5  # 4/5

# --- Database ---------------------------------------------------------------
DB_PATH = "/home/srelias/CottageKiln/kiln_data.db"

# --- REST API ---------------------------------------------------------------
API_HOST = "0.0.0.0"
API_PORT = 8080

# --- ntfy.sh notifications --------------------------------------------------
NTFY_URL = "https://ntfy.sh"
NTFY_TOPIC = "kiln-cottage-abc123"  # choose a unique topic name

# Do not re-notify the same alert code within this window (seconds).
# One-shot alerts (run_complete, equalizing_start, conditioning_start) bypass.
ALERT_SUPPRESS_S = 1800

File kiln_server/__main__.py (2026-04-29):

"""kiln_server entry point.

Wires the SX1278 radio, SQLite database, ntfy notifier, and Flask API
together, then runs until SIGTERM.

Run with:
    python3 -m kiln_server
"""

from __future__ import annotations

import logging
import signal
import sys
import threading
import time

from . import config
from .api import create_app
from .database import Database
from .lora_receiver import LoraReceiver, SX1278
from .notifier import Notifier

log = logging.getLogger("kiln_server")


def _configure_logging() -> None:
    logging.basicConfig(
        level=logging.INFO,
        format="%(asctime)s [%(levelname)s] %(name)s: %(message)s",
        datefmt="%Y-%m-%d %H:%M:%S",
        stream=sys.stdout,
    )


def main() -> int:
    _configure_logging()
    log.info("kiln_server starting (environment=%s)", config.ENVIRONMENT)

    db = Database(config.DB_PATH)
    notifier = Notifier(
        url=config.NTFY_URL,
        topic=config.NTFY_TOPIC,
        suppress_s=config.ALERT_SUPPRESS_S,
    )

    # --- Radio -------------------------------------------------------------
    try:
        radio = SX1278(
            spi_bus=config.SPI_BUS,
            spi_ce=config.SPI_CE,
            rst_pin=config.RST_PIN,
            dio0_pin=config.DIO0_PIN,
            freq_hz=int(config.LORA_FREQ_MHZ * 1_000_000),
        )
    except ImportError as e:
        log.error("kiln_server: Pi-only modules missing (%s). "
                  "Install spidev and RPi.GPIO on the Pi4.", e)
        return 1
    except Exception as e:
        log.exception("kiln_server: failed to open SX1278 radio: %s", e)
        return 1

    radio.reset()
    version = radio.read_reg(0x42)
    if version != 0x12:
        log.error("kiln_server: SX1278 version register=0x%02X (expected 0x12). "
                  "Check wiring and that SPI is enabled.", version)
        radio.close()
        return 1
    log.info("kiln_server: SX1278 detected (ver 0x%02X)", version)
    radio.configure_rx(sf=config.LORA_SF, cr=config.LORA_CR)

    # --- Receiver thread ---------------------------------------------------
    receiver = LoraReceiver(radio=radio, db=db, notifier=notifier)
    receiver.start()

    # --- Flask API ---------------------------------------------------------
    app = create_app(
        db=db,
        receiver=receiver,
        environment=config.ENVIRONMENT,
        notifier=notifier,
    )

    stop_event = threading.Event()

    def _shutdown(signum, frame):
        log.info("kiln_server: signal %d received, shutting down", signum)
        stop_event.set()

    signal.signal(signal.SIGINT, _shutdown)
    signal.signal(signal.SIGTERM, _shutdown)

    # Flask's dev server is fine for a LAN-only, low-QPS API on the Pi4.
    # use_reloader must be False so we stay a single process and signals land
    # on our handler above.
    def _serve() -> None:
        try:
            app.run(
                host=config.API_HOST,
                port=config.API_PORT,
                threaded=True,
                use_reloader=False,
                debug=False,
            )
        except Exception as e:
            log.exception("kiln_server: API server crashed: %s", e)
            stop_event.set()

    api_thread = threading.Thread(target=_serve, name="flask-api", daemon=True)
    api_thread.start()
    log.info("kiln_server: REST API on http://%s:%d",
             config.API_HOST, config.API_PORT)

    # --- Wait for shutdown -------------------------------------------------
    try:
        while not stop_event.is_set():
            time.sleep(1)
    finally:
        log.info("kiln_server: stopping receiver and closing radio")
        receiver.stop()
        receiver.join(timeout=3)
        radio.close()
        db.close()

    log.info("kiln_server: exited cleanly")
    return 0


if __name__ == "__main__":
    sys.exit(main())

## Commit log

2026-03-18 Add vent servo module
2026-03-21 Add KiCad project
    [2PinScrewTerminalBlockConnector.step, 4PinScrewTerminalBlockConnector.step, KilnController.kicad_pcb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]
2026-03-21 Current monitoring WIP
    [KilnController.kicad_pcb, KilnController.kicad_sch]
2026-03-22 Working current monitors, with updated layout
    [INA219 Module.step, KilnController.kicad_pcb, KilnController.kicad_sch]
2026-03-22 Controller and KiCad for SHT31D sensors
    [KilnController.kicad_pcb, KilnController.kicad_sch]
2026-03-22 Heater SSR controller and PCB update
    [KilnController.kicad_pcb, KilnController.kicad_sch]
2026-03-25 Working display driver with schematic and layout
    [KilnController.kicad_pcb, KilnController.kicad_sch]
2026-03-25 Update Display Button GPIO
    [KilnController.kicad_pcb, KilnController.kicad_sch]
2026-04-03 Add LoRa to schematic & layout
    [KilnController.kicad_pcb, KilnController.kicad_sch, LoRa Module.step]
2026-04-08 Remove VBUS connection
    [KilnController.kicad_pcb, KilnController.kicad_sch]
2026-04-08 Add schematic and PCB information to README
    Added section for schematic and custom PCB details.
2026-04-10 PCB V1 before redesign
    [KilnController.kicad_pcb, KilnController.kicad_sch]
2026-04-12 PCB design V2
    [KilnController.kicad_pcb]
2026-04-12 Surface errors from the firmware to API.
    [main.py, test_fault_surfacing.py]
2026-04-13 V3 PBC Design
    [KilnController.kicad_pcb, KilnController.kicad_sch]
2026-04-19 Final PCB for manufacturing
    [KilnController-B_Cu.gbl, KilnController-B_Mask.gbs, KilnController-B_Paste.gbp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]
2026-04-22 Moisture probe calibration screen
